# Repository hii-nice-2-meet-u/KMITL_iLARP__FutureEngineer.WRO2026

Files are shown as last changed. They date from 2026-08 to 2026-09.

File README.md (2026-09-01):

# **KMITL iLARP — WRO Future Engineers 2026**

> Autonomous mobile robot developed by **KMITL iLARP** for the
> **World Robot Olympiad 2026 — Future Engineers** category.

---

## **Team**

**KMITL iLARP** — World Robot Olympiad 2026, Future Engineers category.

The repository identifies the team as **KMITL iLARP**. Individual names and
roles are not stored in the source tree.

## **Robot Images**

The robot combines camera vision, LiDAR, odometry, and model-based control in a
compact four-wheel platform. Explore the complete six-view build below or open
the full-resolution originals in [`v-photos/`](v-photos/).

<table>
  <tr>
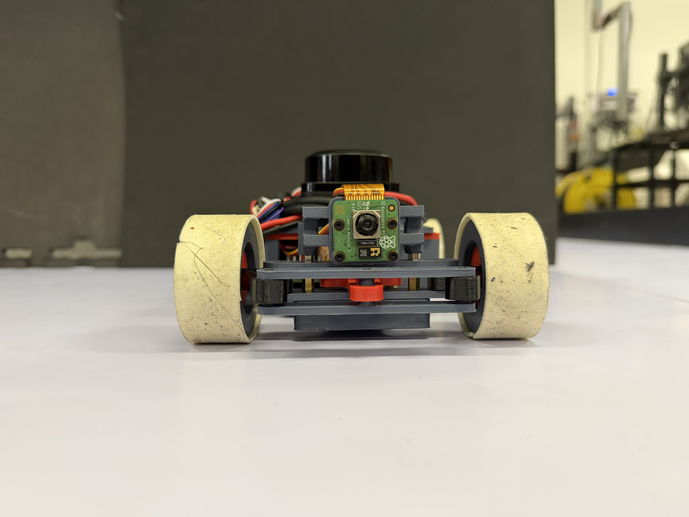
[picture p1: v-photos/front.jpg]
Robot front view
    <td align="center"><br><sub><strong>Front</strong> </sub></td>
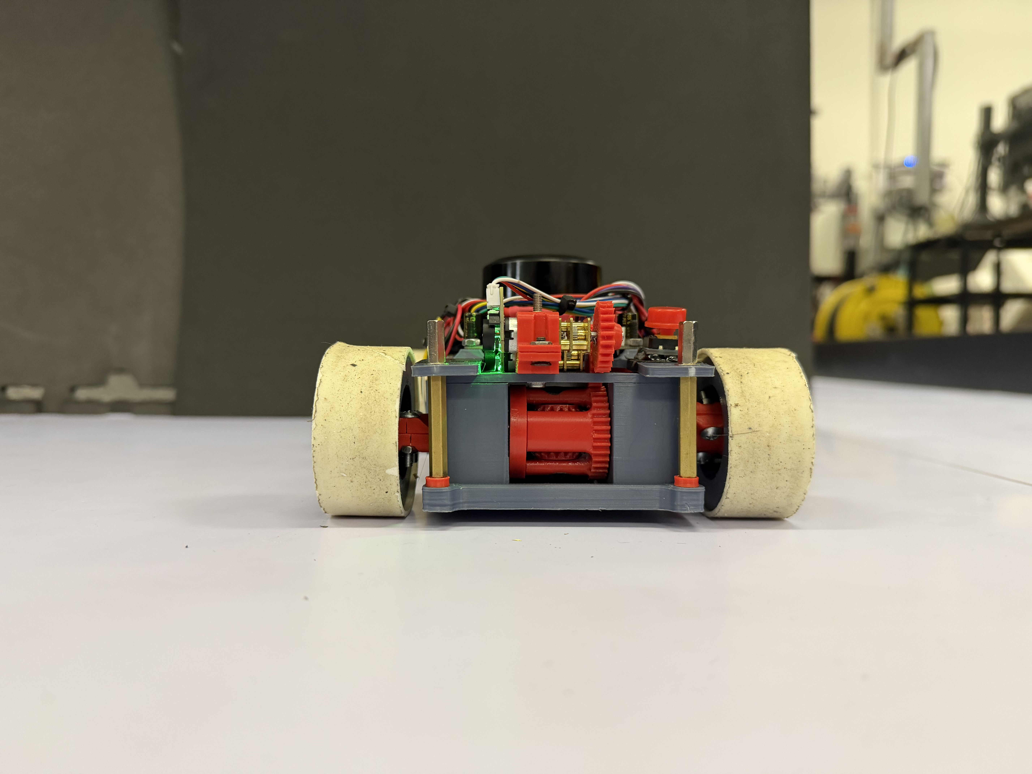
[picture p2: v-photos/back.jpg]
Robot back view
    <td align="center"><br><sub><strong>Back</strong> </sub></td>
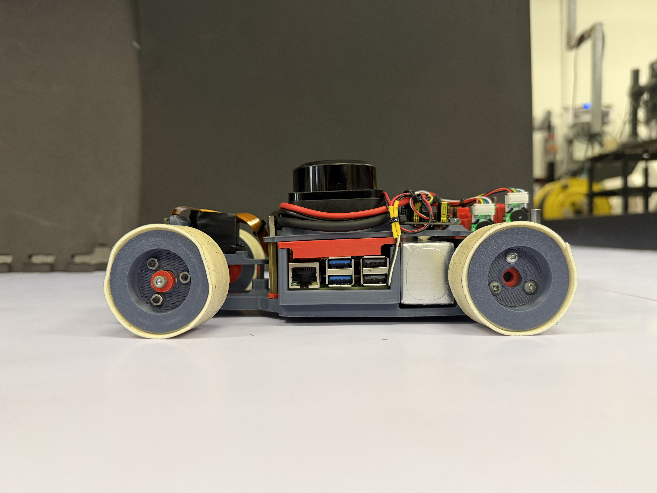
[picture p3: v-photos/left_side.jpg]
Robot left-side view
    <td align="center"><br><sub><strong>Left side</strong> </sub></td>
  </tr>
  <tr>
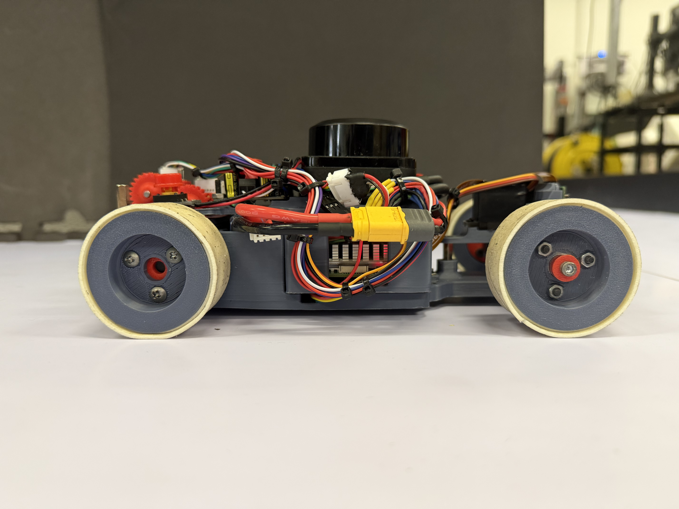
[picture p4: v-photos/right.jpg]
Robot right-side view
    <td align="center"><br><sub><strong>Right side</strong> </sub></td>
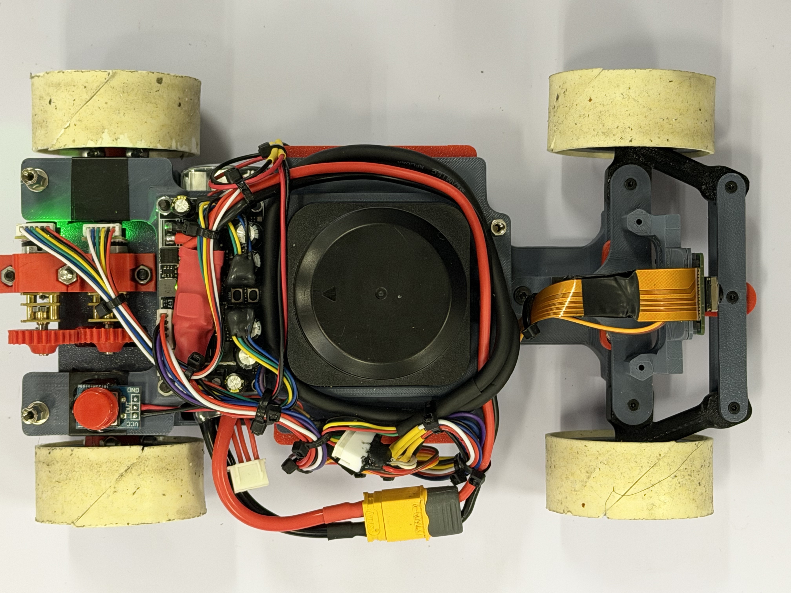
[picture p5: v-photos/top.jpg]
Robot top view
    <td align="center"><br><sub><strong>Top</strong> · Sensor layout</sub></td>
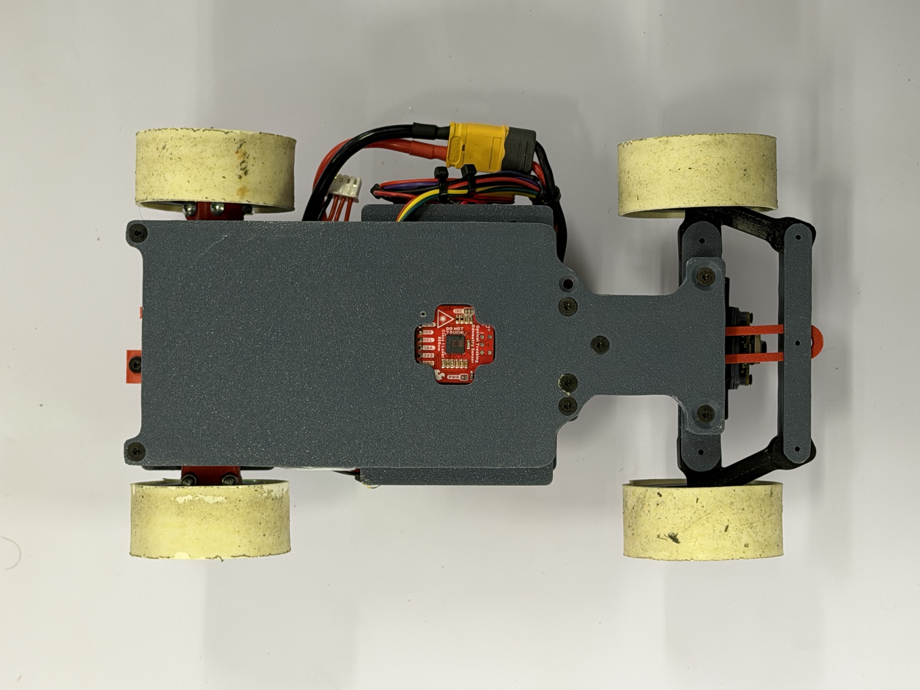
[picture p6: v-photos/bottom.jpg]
Robot bottom view
    <td align="center"><br><sub><strong>Bottom</strong> </sub></td>
  </tr>
</table>

## **Performance Video**

Open Challenge link:

Obstacle Challenge link:

## **Documentation**

Detailed per-subsystem engineering documentation lives in
[`docs/`](docs/README.md). Quick links:
[Vision](docs/vision/README.md) ·
[LiDAR](docs/lidar/README.md) ·
[Odometry](docs/odometry/README.md) ·
[Perception](docs/perception/README.md) ·
[Navigation](docs/navigation/README.md) ·
[Control](docs/control/README.md) ·
[SPI](docs/spi/README.md) ·
[Logging](docs/logging/README.md) ·
[Software Architecture](docs/software/README.md) ·
[Mechanical](docs/mechanical/README.md) ·
[Electronics](docs/electronics/README.md).

---

## **Project Overview**

This project presents the design and implementation of an autonomous mobile robot for the **WRO Future Engineers 2026 competition**.

The system integrates:

- Computer Vision for object detection and classification
- LiDAR-based environment perception
- IMU and odometry for motion stability
- Sensor fusion for robust decision making
- Model-based motion control

The robot is designed to operate in structured track environments while maintaining robustness under dynamic obstacles and varying lighting conditions.

---

## **System Architecture**

```mermaid
flowchart TD
    CAM[Camera] --> CV[Vision Module]
    LIDAR[RPLIDAR S3] --> LIDAR_PROC[LiDAR Module]
    IMU[IMU + Odometry] --> STATE[State Estimation]

    CV --> FUSION[Sensor Fusion Layer]
    LIDAR_PROC --> FUSION
    STATE --> FUSION

    FUSION --> NAV[Navigation System]
    NAV --> CTRL[Motion Controller]

    CTRL --> STEER[Steering]
    CTRL --> DRIVE[Drive Motor]
```

### System Design Philosophy

The system is built on multi-sensor redundancy, where each sensor contributes a different perspective:

1. Camera → semantic understanding (what and where)
2. LiDAR → geometric understanding (distance and structure)
3. IMU + Odometry → motion consistency (stability and heading)

This separation ensures robustness even when one sensor is degraded.

---

## **Computer Vision System**

The vision system is implemented in C++ with OpenCV, using libcamera/LCCV for image acquisition.

### Processing Pipeline

```text
Frame Capture
   ↓
Color Space Conversion (BGR → HSV)
   ↓
Color Segmentation (Red / Green)
   ↓
Morphological Filtering
   ↓
Contour Extraction
   ↓
Geometric Validation
   ↓
Object Classification
   ↓
Bearing Estimation
```

### Output Features

- Object class (red / green obstacle)
- Bounding box
- Image-space position
- Relative bearing angle

Documentation: `docs/vision/README.md`
Source Code: `code/modules/camera`

---

## **LiDAR Perception System**

The robot uses RPLIDAR S3 for environmental geometry sensing.

### Processing Pipeline

```text
Raw Scan Data
   ↓
Point Filtering
   ↓
Polar → Cartesian Conversion
   ↓
Sector Segmentation
   ↓
Statistical Filtering (Median)
   ↓
Wall Estimation
```

### Output Features

- Front distance
- Left / Right distance
- Wall angle estimation
- Track boundary detection

Documentation: `docs/lidar/README.md`
Source Code: `code/modules/lidar`

---

## **IMU and Odometry System**

The motion estimation system combines:

- IMU angular velocity
- Wheel odometry
- Drift correction logic

### Responsibilities

- Heading stabilization
- Short-term pose estimation
- Motion smoothing for control layer

Documentation: `docs/odometry/README.md`
Source Code: `code/modules/otos`

---

## **Navigation System**

The navigation system operates as a state-driven decision engine.

### Open Challenge Strategy

```text
LiDAR Geometry
   ↓
Wall Alignment
   ↓
Track Center Estimation
   ↓
Trajectory Generation
   ↓
Steering Control
```

### Obstacle Challenge Strategy

```text
Camera (Object Detection)
        ↓
LiDAR (Geometry Context)
        ↓
IMU + Odometry (Stability)
        ↓
Sensor Fusion Layer
        ↓
Navigation State Machine
        ↓
Path Decision
```

Documentation: `docs/navigation/README.md` (state machine, corner trajectory, track map)
Source Code: `code/modules/navigation`

---

## **Motion Control System**

The motion controller converts navigation outputs into actuator commands.

### Components

- Steering control (servo-based)
- Drive motor control
- Speed regulation
- Stability correction loop

Documentation: `docs/control/README.md` (PID + Stanley) · `docs/spi/README.md` (STM32 link)
Source Code: `code/control`, `code/modules/spi`

---

## **Software Architecture**

The system is implemented in C++17 and structured into modular components.

```text
code/
├── common/              # direction.hpp (DrivingDirection, TurnDirection)
├── app/
│   ├── _challenge/open/ # open_challenge_main (learn+replay) + actuator
│   ├── test_camera/ test_lidar/ test_perception/ test_otos/ test_spi/
│   └── adjust_HSV/ adjust_white/ camera_tuner/
├── modules/
│   ├── camera/          # CameraModule + CameraProcessor
│   ├── lidar/           # LidarModule + LidarProcessor (walls, obstacles, parking)
│   ├── otos/            # OTOS odometry + LinuxI2C
│   ├── perception/      # camera + LiDAR fusion → FusedObstacle
│   ├── navigation/      # state machine, corner trajectory, init_direction, track_map
│   ├── spi/             # SPI master → STM32 (motor/servo/battery)
│   └── logging/         # async CSV telemetry (Logger V1)
├── control/             # PID + Stanley controllers
├── external/            # git submodules (see .gitmodules)
│   ├── LCCV/ rplidar_sdk/ OTOS/ SparkFunToolkit/
├── utils/               # RingBuffer.hpp
├── build_n_deploy.sh
├── CMakeLists.txt
├── Dockerfile.compile
└── Dockerfile.cross
```

See [`docs/software/README.md`](docs/software/README.md) for the full
architecture, threading model, and module/processor split.

### Core Technologies

| No  | Technology  | Purpose |
| --- | --- | --- |
| 1 | C++17 | Core system implementation |
| 2 | OpenCV | Vision processing |
| 3 | libcamera | Camera interface |
| 4 | LCCV | Camera wrapper |
| 5 | RPLIDAR SDK | LiDAR interface |
| 6 | CMake | Build system |
| 7 | Docker | Cross-platform build environment |

---

## **Build & Deploy**

The robot runs on a **Raspberry Pi 5 (arm64)**. The code is cross-compiled on a
development machine inside Docker and then copied to the Pi — see
[`docs/software/README.md`](docs/software/README.md) for details.

**1. Clone with submodules** (the SDKs under `code/external/` are git
submodules):

```bash
git clone --recurse-submodules <repo-url>
# or, if already cloned:
git submodule update --init --recursive
```

**2. Cross-build and deploy** (edit `PI_USER` / `PI_IP` / `PI_TARGET_DIR` at the
top of the script first):

```bash
cd code
./build_n_deploy.sh          # incremental cross-build + rsync to the Pi
./build_n_deploy.sh cross    # (re)build the cross-compiler Docker image
./build_n_deploy.sh clean    # remove build artifacts
```

The script runs CMake + Ninja (with ccache) inside the `cross-pi` container,
installs to `code/dist/install`, then `rsync`s the result to the Pi over SSH.

The deployment script targets Raspberry Pi 5, but the exact OS image and
runtime package list are not recorded in this repository. The installed Open
Challenge executable is `challenge/open/open_challenge_main`; test and tuning
executables are installed from their corresponding `code/app/*/CMakeLists.txt`.

---

## **Mechanical Design**

The mechanical system is designed in SolidWorks with focus on:

- Compact chassis design
- Stable weight distribution
- Efficient steering geometry
- Modular sensor mounting

### Components

1. Chassis structure
2. Steering mechanism
3. Differential drivetrain
4. Motor mounts
5. Sensor mounts (Camera + LiDAR)

CAD Files: `CAD/`
Documentation: `docs/mechanical/README.md`

---

## **Hardware System**

| No  | Component | Function |
| --- | --- | --- |
| 1 | Raspberry Pi | Main compute unit |
| 2 | Camera | Vision sensing |
| 3 | RPLIDAR S3 | Distance and geometry sensing |
| 4 | IMU | Orientation tracking |
| 5 | Wheel Odometry | Motion estimation |
| 6 | Servo Motor | Steering control |
| 7 | DC Motor | Propulsion |

Documentation: `docs/electronics/README.md`

---

## **Development Tools**

### Vision Tools

- adjust_HSV → color calibration
- adjust_white → white balance tuning
- camera_tuner → camera parameter tuning
- test_camera → camera validation

### LiDAR Tools

- test_lidar → scan validation and debugging

Tools Directory: `code/app/`

---

## **Repository Structure**

```text
KMITL_iLARP__FutureEngineer.WRO2026/
├── CAD/                 # SolidWorks / STEP mechanical models
├── code/
│   ├── common/          # shared enums
│   ├── app/             # challenge programs + test & calibration tools
│   ├── modules/         # camera, lidar, otos, perception, navigation, spi, logging
│   ├── control/         # PID + Stanley
│   ├── external/        # vendored SDKs (git submodules)
│   └── utils/           # RingBuffer
├── docs/
│   ├── vision/  lidar/  odometry/       # perception
│   ├── perception/  navigation/  control/  spi/  logging/   # decision + actuation
│   ├── software/                        # architecture, build/deploy
│   ├── mechanical/  electronics/        # hardware
│   └── resources/                       # images referenced by the docs
├── t-photos/  v-photos/  video/         # required WRO submissions
├── README.md
└── LICENSE
```

---

## **Documentation Structure**

1. Each subsystem has its own documentation
2. Main README acts as system overview only
3. Technical details are separated into modules

Full documentation index: `docs/README.md`

---

## **WRO Future Engineers 2026**

The system is designed under the principle:

> Vision provides semantics, LiDAR provides geometry, IMU provides stability, and fusion enables intelligence.

---

KMITL iLARP — WRO Future Engineers 2026
Autonomous Robotics • Computer Vision • LiDAR • Embedded Systems

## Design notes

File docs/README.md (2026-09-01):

# Documentation Index — KMITL iLARP · WRO Future Engineers 2026

This folder contains the detailed engineering documentation for each subsystem
of the robot. The top-level [`README.md`](../README.md) is the system overview;
the documents below go into the reasoning, parameters, and implementation of
each module.

> **Note on scope.** Every technical document here is derived directly from the
> source code in [`code/`](../../../code). Where a value or rationale is not present
> in the codebase (for example measured current draw or final mechanical
> justification), the document states that limitation instead of inventing a
> measurement.

## Signal flow (current architecture)

```
                 ┌──────────┐   ┌──────────┐   ┌────────┐
   sensors  ───▶ │ camera   │   │ lidar    │   │ otos   │
                 │ module   │   │ module   │   │ (pose) │
                 └────┬─────┘   └────┬─────┘   └───┬────┘
                      ▼              ▼             │
                 CameraProcessor  LidarProcessor   │
                      │              │             │
                      └──────┬───────┘             │
                             ▼                     │
                        ┌──────────┐               │
                        │perception│◀──────────────┤ (pose for world mapping)
                        │ (fusion) │               │
                        └────┬─────┘               │
                             ▼                     ▼
                        ┌─────────────────────────────┐
                        │ navigation_controller        │
                        │  · init_direction (CW/CCW)   │
                        │  · Stanley + PID (control/)   │
                        │  · geometric corner + FF      │
                        │  · track_map (learn/replay)   │
                        └───────────────┬──────────────┘
                                        ▼ NavigationCommand (speed, steering)
                        ┌───────────────────────────────┐
                        │ actuator (open challenge app)  │
                        │  → spi_master → STM32 (motor/servo)
                        └───────────────────────────────┘
                                        │
                        logging/ taps every stage → CSV + events
```

## Subsystem documents

| # | Document | Covers | Source code |
|---|---|---|---|
| 1 | [Vision](vision/README.md) | Camera capture, HSV segmentation, object detection, bearing | [`code/modules/camera`](../../../code/modules/camera) |
| 2 | [LiDAR](lidar/README.md) | Scan acquisition, line fitting, wall/obstacle/parking resolution | [`code/modules/lidar`](../../../code/modules/lidar) |
| 3 | [Odometry](odometry/README.md) | SparkFun OTOS optical pose over I²C | [`code/modules/otos`](../../../code/modules/otos) |
| 4 | [Perception (fusion)](perception/README.md) | Camera↔LiDAR association, obstacle colour, world mapping | [`code/modules/perception`](../../../code/modules/perception) |
| 5 | [Navigation](navigation/README.md) | State machine, corner trajectory, direction search, track map | [`code/modules/navigation`](../../../code/modules/navigation) |
| 6 | [Control](control/README.md) | PID + Stanley steering controllers | [`code/control`](../../../code/control) |
| 7 | [SPI link](spi/README.md) | RPi ↔ STM32 command protocol | [`code/modules/spi`](../../../code/modules/spi) |
| 8 | [Logging](logging/README.md) | Async CSV telemetry, events, walls, corners | [`code/modules/logging`](../../../code/modules/logging) |
| 9 | [Software Architecture](software/README.md) | Module/processor split, threading, build & deploy | [`code/`](../../../code) |
| 10 | [Mechanical](mechanical/README.md) | Chassis, steering, drivetrain, CAD inventory | [`CAD/`](../../../CAD) |
| 11 | [Electronics](electronics/README.md) | Compute, sensors, wiring, power budget | — |

## How this maps to the WRO documentation rubric (Appendix C)

The WRO Future Engineers rubric scores the repository on five criteria
(0/2/4/6 each, 30 total):

| Rubric criterion | Where to look |
|---|---|
| 1. Mobility & mechanical design | [Mechanical](mechanical/README.md) |
| 2. Power & sensor architecture | [Electronics](electronics/README.md), [Odometry](odometry/README.md) |
| 3. Software architecture & obstacle strategy | [Navigation](navigation/README.md), [Control](control/README.md), [Perception](perception/README.md), [Vision](vision/README.md), [LiDAR](lidar/README.md) |
| 4. Systems thinking & engineering decisions | "Decision log" sections in each document |
| 5. Reproducibility & GitHub quality | This index + per-module READMEs + top-level README |

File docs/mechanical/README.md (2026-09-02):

# Mechanical Design

Chassis, steering, and drivetrain of the robot, and an inventory of the CAD
files that describe them.

**CAD files:** [`CAD/`](../../../../CAD) (SolidWorks `.SLDPRT`/`.SLDASM` +
neutral `.STEP`/`.stp`)

---

## 1. Design goals

The mechanical platform is built around four goals stated in the top-level
README:

- compact chassis that fits within the WRO Future Engineers size limits,
- stable weight distribution for predictable handling,
- efficient steering geometry,
- modular mounts so the camera and LiDAR can be positioned and re-positioned.

---

## 2. Drivetrain

A **rear differential drive** driven by **two** N20 gear-motors mounted
mirror-imaged onto a common input, feeding a purpose-built differential gearset:

- **Motors:** two N20 gear-motors (`CAD/Motor_N20.SLDPRT`, instanced twice in
  the assembly). The pair was adopted to supply drive torque the earlier
  single-motor layout could not. Because they are mounted mirrored, their output
  shafts turn in opposite directions for the same electrical command, and the
  firmware accounts for the inversion; they are **not** one-motor-per-wheel.
- **Differential:** custom-designed gearset in
  [`CAD/DifferentialGear`](../../../../CAD/DifferentialGear):
  - `DifferentialGear__RingGear.SLDPRT` + `...RingGearCap.SLDPRT`
  - `DifferentialGear__Pinions.SLDPRT`
  - `DifferentialGear__SideGear.SLDPRT`
  - `Nut__M3_L27.5_.SLDPRT`

A differential lets the two driven wheels rotate at different speeds through a
turn, avoiding the scrubbing and heading disturbance a locked axle would cause.
The two motors join *before* the differential, at its input, so differential
action between the left and right wheels is preserved.

---

## 3. Steering

Front steering actuated by an **MG90S** micro servo. The steering linkage
knuckles are in [`CAD/MG90`](../../../../CAD/MG90):

- `MG90S_Servo.STEP` — the servo (source: GrabCAD, see `CAD/MG90/soures.txt`)
- `ShoulderUnidirectional.STEP`
- `Shoulder_BiDirectional.STEP`
- `Shoulder_FourDirected.STEP`

The multiple "shoulder" variants are steering-knuckle iterations — evidence of
design iteration on the steering geometry.

---

## 4. Sensor & component mounting

CAD models of the mounted hardware are included so the assembly and sensor
positions are fully described:

| Component | CAD file |
|---|---|
| RPLIDAR S3 | `CAD/RPLIDAR_S3.SLDASM` / `.stp` |
| Raspberry Pi Camera Module 3 | `CAD/RaspburryPi_Camera_Module3.SLDPRT` |
| SparkFun OTOS (PAA5160E1, SEN-24904) | `CAD/SparkFunOpticalTrackingOdometrySensor_...SLDPRT` / `.step` |
| CN3903 (power module) | `CAD/CN3903.SLDASM` / `.STEP` |
| Bearings | `CAD/Bearing_MR128ZZ.SLDPRT`, `CAD/Bearing_MR63ZZ.SLDPRT` |
| Fasteners | `CAD/Nut__M3_Female_.SLDPRT`, `CAD/NutRing__3M.SLDPRT` |
| Test object (marker stand-in) | `CAD/Object/BOX_5x5x10__.SLDPRT` / `.STEP` |

---

## 5. Decision log (rubric criterion 1)

Already inferable from the CAD:

- **Differential drive** — allows different wheel speeds in turns, reducing tire
  scrub and heading upset compared with a fixed axle.
- **Servo-steered front axle (Ackermann-style)** with a dedicated linkage,
  rather than skid/differential steering — closer to a real "self-driving car"
  and matches the category's kinematics focus.
- **Custom differential + iterated steering shoulders** — the multiple shoulder
  versions show the geometry was revised, not adopted blindly.

The CAD directory contains SolidWorks and STEP source files, including several
steering-linkage iterations. It does not contain exported renders, STL files,
measured dimensions, mass, motor gearing data, torque/speed tests, or a weight
distribution record. Those values must be taken from the final assembled robot;
they are not inferred here from filenames or CAD metadata.

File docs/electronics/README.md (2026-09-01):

# Electronics & Power

Compute, sensing, and actuation hardware, how it is wired, and the power budget.

---

## 1. Component overview

| # | Component | Role | Interface | CAD / ref |
|---|---|---|---|---|
| 1 | Raspberry Pi 5 (arm64) | Main compute (perception, navigation) | — | deploy target in `build_n_deploy.sh` |
| 2 | STM32 (MCU) | Real-time actuation: motor + servo + battery | SPI slave | Exact part number is not recorded in the source tree |
| 3 | Raspberry Pi Camera Module 3 | Vision sensing | CSI (libcamera) | `CAD/RaspburryPi_Camera_Module3.SLDPRT` |
| 4 | RPLIDAR S3 | Distance & geometry sensing | UART `/dev/ttyAMA0` @ 1 Mbaud | `CAD/RPLIDAR_S3.SLDASM` |
| 5 | SparkFun OTOS (PAA5160E1) | Optical odometry (pose) | I²C | `CAD/SparkFunOpticalTracking...SLDPRT` |
| 6 | CN3903 | Power / battery management | — | `CAD/CN3903.SLDASM` |
| 7 | MG90S servo | Steering actuator | PWM (driven by STM32) | `CAD/MG90/MG90S_Servo.STEP` |
| 8 | N20 gear-motor | Drive / propulsion | motor driver (driven by STM32) | `CAD/Motor_N20.SLDPRT` |

The compute is **split**: the Pi 5 runs perception + navigation; a separate
**STM32** executes the low-level motor/servo commands and reports battery
voltage, connected to the Pi over **SPI** (15 MHz, mode 0). Camera, LiDAR, and
OTOS have driver modules on the Pi; the servo and motor are commanded through the
SPI link — see the [SPI doc](../spi/README.md).

---

## 2. Software ↔ hardware map

| Subsystem | Hardware | Bus / port | Code |
|---|---|---|---|
| Vision | Camera Module 3 | CSI via libcamera/LCCV | [`modules/camera`](../../../../code/modules/camera) |
| LiDAR | RPLIDAR S3 | UART `/dev/ttyAMA0`, 1,000,000 baud | [`modules/lidar`](../../../../code/modules/lidar) |
| Odometry | OTOS | I²C (`/dev/i2c-*`) | [`modules/otos`](../../../../code/modules/otos) |
| Actuation link | STM32 | SPI master (15 MHz, mode 0) | [`modules/spi`](../../../../code/modules/spi) |
| Steering | MG90S servo | PWM from STM32 (pulse 1000–2100 µs) | via SPI `SERVO_PULSE` |
| Drive | N20 motor | motor driver from STM32 | via SPI `M1_POW` |

---

## 3. Wiring diagram

The repository does not contain a wiring drawing. The electrical topology
implemented by the software is: battery and regulation feed the Pi, camera,
LiDAR, and OTOS; the Pi communicates with the STM32 over SPI; and the STM32
drives the motor and steering servo. Pin-level wiring and voltage rails must be
checked against the assembled robot before publication.
>
The final wiring record should show, at minimum: battery → CN3903 / regulation
→ Pi 5, and how the camera (CSI), LiDAR (USB), OTOS (I²C), servo (PWM), and
motor driver are connected, including voltage rails.

---

## 4. Power budget

The source tree does not include measured current data or a battery
specification, so a numerical power budget would be misleading. Record the
values from the assembled hardware before using this table for electrical
sign-off:

| Load | Voltage | Typical current | Peak current | Notes |
|---|---|---|---|---|
| Raspberry Pi 5 | 5 V | not recorded | not recorded | Higher under CV load |
| RPLIDAR S3 | not recorded | not recorded | not recorded | Motor + sensor |
| Camera Module 3 | 3.3 V | not recorded | not recorded | CSI camera power is supplied by the Pi |
| OTOS | 3.3 V | not recorded | not recorded | I²C sensor |
| MG90S servo | not recorded | not recorded | not recorded | Stall current matters |
| N20 motor | not recorded | not recorded | not recorded | Via driver |
| **Total** | | **not calculated** | **not calculated** | |

Also state: **battery** chemistry / voltage / capacity (mAh), how it is
regulated (the CN3903 / any buck converters), and the resulting **estimated run
time**.

---

## 5. Calibration & noise considerations

The vision intrinsics currently live in `camera_processor.hpp`. The repository
does not include the calibration record. OTOS mounting offsets, electrical-noise
mitigation, grounding, shielding, and lighting tests are also not recorded and
must be documented from the assembled robot and its test results.

---

## 6. Decision log (rubric criterion 2 & 4)

Already visible in the code:

- **Raspberry Pi 5 as sole compute** — enough headroom to run OpenCV vision and
  LiDAR geometry on-board; cross-compiled to keep the Pi free of build load.
- **RPLIDAR at 1 Mbaud over USB serial** — the S3's rate for dense scans.
- **OTOS on I²C in meters/radians** — matches LiDAR/camera units for fusion.

The split architecture keeps perception and navigation on the Pi while the
STM32 handles time-sensitive actuation. Camera, LiDAR, and OTOS provide
complementary semantic, geometric, and motion information. Current, weight,
and processing-time measurements are not stored in the source tree.

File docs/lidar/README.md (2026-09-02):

# LiDAR System

Turns raw 2-D laser scans into a compact geometric description of the track:
the left, right, and front walls, plus any obstacle markers standing inside the
lane.

**Source code:** [`code/modules/lidar`](../../../../code/modules/lidar)
· Acquisition: [`lidar_module.cpp`](../../../../code/modules/lidar/lidar_module.cpp)
· Processing: [`lidar_processor.cpp`](../../../../code/modules/lidar/lidar_processor.cpp)
· Shared types: [`lidar_struct.hpp`](../../../../code/modules/lidar/lidar_struct.hpp)

Sensor: **RPLIDAR S3** (SLAMTEC), driven through the official `rplidar_sdk`.

### Physical mount convention

The assembled robot mounts the RPLIDAR with its raw-angle-zero arrow pointing
to the rear. RPLIDAR's raw 0° is the direction of that arrow, so the robot's
front is raw 180°. `polar2cartesian()` intentionally applies the 180° mount
compensation (`x = -d·sin(angle)`, `y = -d·cos(angle)`), leaving **+Y as the
robot-forward axis**. This was confirmed by M-1 on 2026-09-02; do not remove
the minus signs.

---

## 1. Responsibilities

Like the vision subsystem, LiDAR is split into acquisition and processing:

- **`LidarModule`** — owns the serial connection and the scan thread. It
  converts the SDK's fixed-point measurement nodes into plain
  `LidarPoint{angle_deg, distance_m, quality}` values and publishes timestamped
  scans.
- **`LidarProcessor`** — a stateless pipeline that converts one scan into
  `ProcessedLidarData`: fitted line segments, resolved walls, and obstacle
  segments.

---

## 2. Acquisition (`LidarModule`)

| Parameter | Default | Notes |
|---|---|---|
| Serial port | `/dev/ttyUSB0` (module default) | The Open Challenge apps use `/dev/ttyAMA0` (Pi GPIO UART) |
| Baud rate | 1,000,000 | RPLIDAR S3 |
| Buffer | `RingBuffer<TimedLidarData, 10>` | Newest-wins |

Flow (`lidar_module.cpp`):

1. `initialize()` creates a serial channel and the SLAMTEC driver, then
   `connect()`s. Failures are reported and cleaned up.
2. `start()` sets the motor speed and calls `startScan()`, then spawns
   `scan_loop()` on its own thread.
3. `scan_loop()` repeatedly `grabScanDataHq()` → `ascendScanData()` (sort by
   angle) → `processScan()`.
4. **Health watchdog.** If `grabScan` fails 3 times in a row, `checkHealth()` is
   queried and the device health / error code is logged. This surfaces motor or
   comms problems instead of silently stalling.

### Fixed-point conversion

The SDK returns fixed-point fields, converted in `processScan()`:

```
angle_deg   = angle_z_q14 * 90 / 2^14
distance_m  = dist_mm_q2 / 1000 / 2^2
quality     = node.quality
```

Consumers use `get_latest()` (non-blocking) or `wait_for_data()` (blocks until a
new scan), the same pattern as the camera module.

---

## 3. Processing pipeline (`LidarProcessor`)

```
TimedLidarData (polar points)
   │
   ▼  filter invalid points (quality, min distance)
   ▼  polar → cartesian
Cartesian points
   │
   ▼  split-and-merge → point groups
   ▼  PCA line fit per group → LineSegment
   ▼  merge collinear aligned segments
Line segments
   │
   ├─▶ resolve_track_walls → left / right / front walls
   ├─▶ find_parking_wall  → optional parking-lot wall
   └─▶ detect_obstacles   → obstacle markers (with bearing_rad())
ProcessedLidarData
```

`ProcessedLidarData` now carries `line_segments`, `walls` (`ResolvedWalls`), an
optional `parking_wall`, and `obstacles`. Each `ObstacleObject` exposes
`bearing_rad() = atan2(center.x, center.y)`, which the perception layer uses to
associate it with a camera detection.

### 3.0 Motion deskew (P-22 enabled)

Each scan is deskewed into its scan-end frame using the measured OTOS forward
velocity, yaw rate, and LiDAR revolution period. M-1 confirms that forward is
robot +Y, matching the sign in `LidarProcessor::deskew()`. The first scan, which
has no measured period yet, intentionally remains un-deskewed.

The old controller-injected `wall_correction_rad` path has been removed from
LiDAR processing. Geometry is no longer rotated using the navigation target
heading; the telemetry field is retained as a deprecated zero column for CSV
schema compatibility.

### 3.1 Point filtering & coordinate frame

`process()` now takes the tuning constants and optional `ScanMotion`; it no
longer accepts `heading_error_rad`. Full signature:

```cpp
process(data, min_segment_point = 5, max_line_error_m = 0.035,
        max_point_gap_m = 0.10, max_angle_diff = 3.0,
        max_collinear_error_m = 0.03, max_segment_gap_m = 0.05,
        motion = ScanMotion{})
```

> **Logged geometry is now in the deskewed robot frame.** The deprecated
> `wall_correction_rad` telemetry column is always zero after P-22; it remains
> only to preserve the existing CSV column layout.

`is_valid_point()` drops points with `quality < 10`, non-finite range/angle,
`distance < 0.015 m`, or `distance > 3.0 m`. The decision lives in
`classify_point()`, which also tags each rejection as quality- or range-based so
the per-scan `lidar_points_rejected_quality`/`_range` telemetry counts a mis-set
threshold without persisting the raw scan.

`polar2cartesian()` uses the robot frame **+X = right, +Y = forward**:

```
x = distance · sin(angle)
y = distance · cos(angle)
```

### 3.2 Split-and-merge line fitting

Implemented recursively in `split_line_segments_recursive()`. For a run of
points it:

1. **Gap split** — if the distance between two consecutive points exceeds
   `MAX_POINT_GAP_M`, split there (the wall is not continuous).
2. **Deviation split** — otherwise find the point farthest from the
   straight line joining the run's endpoints; if that deviation exceeds
   `MAX_LINE_ERROR_M`, split at that point (Douglas–Peucker style).
3. Otherwise the run is accepted as one segment.

Runs shorter than `MIN_SEGMENT_POINTS` are discarded.

| Constant | Value |
|---|---|
| `MIN_SEGMENT_POINTS` | 5 |
| `MAX_LINE_ERROR_M` | 0.035 m |
| `MAX_POINT_GAP_M` | 0.11 m |

### 3.3 Line fitting (`fit_line_segment`)

Each accepted group is fitted with **total least squares (PCA)**, not ordinary
least squares, so vertical walls are handled correctly:

```
θ = 0.5 · atan2( 2·Sxy , Sxx − Syy )
```

The segment stores its direction/normal, the line constant `c`, its two
projected endpoints, and its **RMS error**. Segments whose RMS error exceeds
`MAX_LINE_ERROR_M` are rejected after fitting as well.

### 3.4 Merging aligned segments (`merge_aligned_segments`)

A real wall often breaks into several segments. Two segments are merged when
**all** of these hold:

| Test | Threshold |
|---|---|
| Angle difference | ≤ 5° |
| Collinearity (perp. distance of one center to the other's line) | ≤ 0.02 m |
| End-to-end gap | ≤ 0.05 m |

The merged segment spans the extreme projections of all four endpoints along the
common direction.

### 3.5 Resolving walls (`resolve_track_walls`)

Segments longer than `MIN_WALL_LENGTH_M = 0.25 m` are classified by orientation
(within `±15°`):

- **Vertical-ish** segments → **left** wall if their center x < 0, else
  **right** wall.
- **Horizontal-ish** segments with center y > 0 → **front** wall.

For each side the wall with the **smallest perpendicular distance** (i.e. the
closest) wins. The result is a `ResolvedWalls{left, right, front}`, each
optional.

`resolve_inner_outer()` maps left/right to **inner/outer** depending on the
`DrivingDirection` (CLOCKWISE vs COUNTER_CLOCKWISE), so the same logic works
regardless of which way the round is run.

### 3.6 Obstacle detection (`detect_obstacle_segments`)

A segment is treated as an obstacle marker only if it is **not** part of a wall
and is the right size:

- rejected if it *is* one of the resolved walls (`is_same_segment`) or is a
  fragment lying on a wall (`is_wall_fragment`);
- kept only if `0.028 m ≤ length ≤ 0.08 m` and its center is in front
  (`y > 0`);
- nearby detections (within 0.08 m) are merged so one marker yields one
  obstacle.

| Constant | Value |
|---|---|
| `MIN_OBSTACLE_SEGMENT_LENGTH_M` | 0.028 m |
| `MAX_OBSTACLE_SEGMENT_LENGTH_M` | 0.08 m |
| `SAME_OBSTACLE_DISTANCE` | 0.08 m |
| Wall-fragment max distance | 0.04 m |

---

## 4. Debug tools

- [`code/app/test_lidar`](../../../../code/app/test_lidar) renders a top-down debug map
  (1 m = 300 px): raw segments in gray, resolved walls in green, obstacles in
  red with distance/bearing labels, plus per-frame processing time.
- [`code/app/test_perception`](../../../../code/app/test_perception) exercises the
  full LiDAR + camera **fusion** path — see the
  [Perception](../perception/README.md) doc.

These are the main tools for verifying the pipeline against a real track.

---

## 5. Decision log (rubric criterion 4)

Already visible in the code:

- **Split-and-merge + PCA** instead of a Hough transform — gives explicit,
  bounded line segments with endpoints and an RMS error to threshold on, which
  is exactly what wall/obstacle resolution needs.
- **Total least squares** rather than y-on-x least squares — the latter blows up
  for near-vertical walls (infinite slope); TLS does not.
- **Closest-segment-wins** for wall selection — the nearest parallel surface is
  the actual track wall; farther parallel returns are noise or the opposite
  wall.
- **Inner/outer abstraction** — decouples the geometry from the run direction so
  navigation logic is written once.

The thresholds are defined in `LidarProcessor::process()` and describe the
current geometric filters. The repository contains no tuning log, measured
processing rate, real-track scan count, or failure-case report, so those values
are not presented as measured performance here.

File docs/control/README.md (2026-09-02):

# Control

Low-level controllers used by the navigation layer: a general PID and a Stanley
lateral controller built on top of it.

**Source code:** [`code/control`](../../../../code/control)
· PID: [`pid.cpp`](../../../../code/control/pid.cpp) / [`pid.hpp`](../../../../code/control/pid.hpp)
· Stanley: [`stanley_controller.cpp`](../../../../code/control/stanley_controller.cpp) / [`.hpp`](../../../../code/control/stanley_controller.hpp)

---

## 1. PID (`control::PID`)

A reusable PID with the safety features a real control loop needs:

- **Output clamping** — `min_output` / `max_output`.
- **Integral anti-windup** — the integral term is clamped to
  `min_integral` / `max_integral`, so it cannot wind up while the output is
  saturated.
- **dt handling** — `calculate(setpoint, current)` measures `dt` from a
  `steady_clock`; an explicit `calculate(setpoint, current, dt_s)` overload is
  used when the caller already has a timestep. `dt` is guarded by `max_dt_s`
  (default 0.10 s) so a long gap between calls cannot cause a derivative spike.
- **`reset()`** clears the integral and derivative history between runs.

`PIDConfig` fields: `kp, ki, kd, min_output, max_output, min_integral,
max_integral, max_dt_s`.

The navigation layer instantiates PID **twice**, with different gains, for:
heading hold during a corner (`turn_heading_pid`) and inside the Stanley
controller (`heading_pid`).

> A third instance, `speed_pid` (speed→acceleration), was removed. Its output
> reached no actuator: `ActuatorOutput::apply()` converts `target_speed_mps`
> straight to a motor-RPM command, and the STM32 runs its own closed speed
> loop, so the Pi-side acceleration request was dead code (audit finding F-09).
> Speed on the Pi side is shaped only by the `max_acceleration_mps2` /
> `max_deceleration_mps2` rate limits in `condition_command()`.

---

## 2. Stanley controller (`control::StanleyController`)

Standard Stanley steering law for the Ackermann front axle:

```
delta = heading_error
      + atan2( k · cross_track_error , speed + softening_speed )
```

- **`k`** (cross-track gain, default 1.0; Open Challenge uses 0.85) — how hard to
  correct lateral error.
- **`softening_speed_mps`** (0.20) — prevents divide-by-near-zero and overly
  aggressive steering at low speed.
- **`max_steering_rad`** (default 30°; Open Challenge widens to 45°) — physical
  steering limit; the output is clamped to it.
- The **heading term** is stabilised by an internal PID (`heading_pid`) rather
  than used raw, which damps oscillation.

Sign convention: **negative = LEFT, positive = RIGHT**, matching the navigation
and actuator layers.

---

## 3. Decision log (rubric criterion 4)

Visible in the code:

- **Stanley over pure-pursuit** — Stanley references the front axle and handles
  both cross-track and heading error directly, which suits a wall-following car
  with a LiDAR-measured wall line.
- **PID as a shared primitive** — one well-tested implementation (with
  anti-windup and dt guarding) is reused for heading, speed, and the Stanley
  heading term, instead of three ad-hoc loops.
- **Speed-softened cross-track term** — keeps steering sane at the low speeds
  used in SEARCH_DIRECTION and corner exits.

The source tree records the active gains and logs both raw and shaped steering,
but it does not include step-test results, a before/after comparison, or plots.
Those records should be added only from actual track runs.

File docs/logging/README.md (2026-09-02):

# Logging & Telemetry

Records what the robot sensed, decided, and commanded on every run, so behaviour
can be analysed and re-tuned offline without a debugger on the track.

**Source code:** [`code/modules/logging`](../../../../code/modules/logging)
· Async writer: [`async_csv_writer.cpp`](../../../../code/modules/logging/async_csv_writer.cpp)
· Row types & CSV: [`log_types.cpp`](../../../../code/modules/logging/log_types.cpp) / [`.hpp`](../../../../code/modules/logging/log_types.hpp)
· Loggers: [`telemetry_logger.cpp`](../../../../code/modules/logging/telemetry_logger.cpp), [`wall_logger.cpp`](../../../../code/modules/logging/wall_logger.cpp), [`segment_logger.cpp`](../../../../code/modules/logging/segment_logger.cpp)
· Run metadata: [`run_metadata.cpp`](../../../../code/modules/logging/run_metadata.cpp)
· Offline tools: [`code/tools`](../../../../code/tools)

---

## 1. Design goal

Logging must **not** slow the control loop. All file I/O is pushed to a
background thread; the control thread only enqueues rows.

---

## 2. `AsyncCsvWriter` — the backbone

- Opens a CSV file, writes the header, and spawns a **worker thread**.
- `push(row)` appends to an in-memory queue under a mutex and returns
  immediately.
- The queue is **bounded** (`maximum_queued_rows = 400`, drop-oldest): if the
  disk can't keep up, the oldest rows are dropped and counted rather than
  blocking the robot.
- A background **flush every 1 s** limits data loss on a crash without putting
  I/O on the control thread.
- Write failures are latched and reportable (`has_write_error()`).

> **Durability note:** `flush()` provides OS page-cache durability, not
> `fsync`-level guarantees. A power cut can still lose the last unflushed rows,
> plus whatever remained in the in-memory queue.

---

## 3. The missing-value convention (read this first)

The one rule the schema depends on, documented at the top of `log_types.hpp`:

> **A numeric column of `0` means "measured, and the value was zero" — never
> "not measured".** Any group that can be absent carries a paired `*_valid`
> boolean, written in **every** navigation mode, not only the mode that computes
> it. Consumers must gate on the flag before plotting or averaging.

This exists because the controller builds a fresh `NavigationDebug` each tick, so
an unwritten field would otherwise log a plausible `0`. Before this was enforced,
wall distances read `0` through every corner and made plots look broken. Key
pairs: `outer_distance_m`/`outer_wall_valid`, `inner_distance_m`/
`inner_wall_valid`, `distance_error_m`/`wall_following_active`,
`effective_turn_trigger_m` & `wall_corner_*`/`turn_trigger_evaluated`,
`battery_voltage_v`/`battery_valid`, `camera_process_us`/`camera_process_valid`.
Absence is **never** encoded as `NaN` (it parses inconsistently across tools).

---

## 4. Per-run outputs

Each run gets its own directory (`make_run_directory("logs")`), containing:

| File | Row type | Cadence | Purpose |
|---|---|---|---|
| `run_meta.json` | — | once at start (+ drop counts at exit) | provenance: git commit/dirty, build time, executable, telemetry field count, full config dump (navigation/stanley/PID/actuator, and perception/obstacle for the obstacle app), OTOS scalars actually applied |
| `telemetry.csv` | `TelemetryRow` | per tick (~20 Hz) | full per-tick state (§5) |
| `walls.csv` | `WallRow` | **every mode** | resolved wall segments, with a `mode` column to filter |
| `segments.csv` | `SegmentRow` | every mode | **all** fitted line segments (not just the 3 resolved walls), each tagged LEFT/RIGHT/FRONT/NONE — debugs a mis-classified wall offline |
| `corners.csv` | `CornerRow` | on exit | `TrackMap` corner landmarks snapshot |
| `events.log` | (EventLogger) | sparse | mode transitions and faults, timestamped from run start |

A run **refuses to start** if `run_meta.json` cannot be written — an
unattributable log is worse than none. Drop counts for all three async writers
(telemetry, walls, events) are printed at exit and recorded back into
`run_meta.json`.

---

## 5. `TelemetryRow` contents (94 columns)

Grouped by what each group answers. Every group follows §3.

- **Pose & motion:** `pos_x_m, pos_y_m, heading_rad, measured_speed_mps`.
- **Raw OTOS channels:** `pose_timestamp_us` (same `steady_clock` epoch as the
  LiDAR scan, so scan-to-pose skew is measurable), `otos_velocity_x/y_mps`,
  `otos_yaw_rate_rps`, `otos_accel_x/y_mps2` — the signed velocity, yaw rate and
  acceleration the controller's unsigned `hypot` speed throws away.
- **Wall following:** `outer_distance_m, inner_distance_m, distance_error_m,
  wall_angle_rad, angle_error_rad` + validity flags; `wall_correction_rad` (the
  heading de-rotation applied before classification — subtract to recover raw
  geometry).
- **Turn & corner tracking:** `heading_error_rad, turn_progress,
  turn_feedforward_rad, effective_turn_trigger_m, wall_corner_*`,
  `turn_trigger_source/frames/armed/evaluated`, `replay_gate_suppressed`.
- **Controller internals:** Stanley cross-track/heading terms and integral,
  turn-heading PID output/integral — so PID gains are tunable from a log, not
  only from the summed command.
- **Raw vs shaped command:** `raw_steering_rad` vs `steering_rad`,
  `raw_target_speed_mps` vs `target_speed_mps` — makes the conditioning stage
  tunable.
- **Timing:** `update_dt_s` (clamped) and `raw_update_dt_s` (pre-clamp);
  `lidar_process_us`, `camera_process_us` (per-stage wall-clock).
- **Battery:** `battery_voltage_v` + age, sampled ~1 Hz (blocking SPI read).
- **Obstacle avoidance & fusion:** obstacle active/colour/side/geometry/world
  position; camera-LiDAR fusion counts; `lidar_points_total` and the
  `rejected_quality`/`rejected_range` tallies (a mis-set LiDAR threshold shows
  up here without persisting the raw scan).
- **Actuator output:** `wheel_rpm`, `servo_pulse_us` (sent) and
  `commanded_servo_pulse_us` (pre-step-limit — reveals when `maximum_servo_step_us`
  is clipping). Empty for monitor-only apps.

---

## 6. Clean shutdown

`install_stop_signal_handlers()` / `notify_stop_requested()` let a
`SIGINT`/`SIGTERM` stop a run cleanly — the challenge apps call
`notify_stop_requested()` from their signal handler so the writer threads flush
and join instead of being killed mid-write. `SIGKILL` cannot be caught and loses
the flush interval plus the in-memory queue.

---

## 7. Offline tools ([`code/tools`](../../../../code/tools))

- **`plot_run.py <telemetry.csv> [out]`** — top-down map (speed-coloured
  trajectory, obstacles, per-lap overlay) plus validity-gated signal time series.
  Reads columns from the file header and gates each series on its `*_valid` flag,
  so it renders old and new schemas and draws gaps, not false zeros.
- **`check_run.py <run_dir>`** — automated QA; non-zero exit on any failure.
  Flags per-mode zero-fill, `row_index` gaps, writer drop counts, `dt` outliers,
  a `measured/target` speed ratio outside `[0.85, 1.15]`, header/`run_meta`
  field-count mismatch, and value/validity-flag contradictions.

---

## 8. Decision log (rubric criterion 4)

- **Async, bounded, drop-oldest** — logging never blocks or grows unbounded;
  under I/O pressure the robot keeps driving and the loss is measured.
- **Evidence, not conclusions** — every tier-2 value is a function of the raw
  inputs plus the config; the missing-value convention keeps "not measured"
  distinct from "measured zero".
- **Per-run provenance** — `run_meta.json` makes a log attributable to an exact
  build and config, so a plot from two weeks ago is still interpretable.
- **Raw + shaped signals together** — makes control/tuning data-driven.
- **Geometry logged in every mode** — walls and segments are no longer
  NORMAL-only, so corners and direction search are debuggable too.

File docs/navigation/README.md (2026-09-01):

# Navigation

The decision-making core of the robot. It consumes processed LiDAR (walls,
obstacles) plus the OTOS heading/speed, and produces a `NavigationCommand`
(target speed, steering angle, target acceleration) for the actuator layer.

**Source code:** [`code/modules/navigation`](../../../../code/modules/navigation)
· State machine: [`navigation_controller.cpp`](../../../../code/modules/navigation/navigation_controller.cpp) / [`.hpp`](../../../../code/modules/navigation/navigation_controller.hpp)
· State types: [`navigation_state.hpp`](../../../../code/modules/navigation/navigation_state.hpp)
· Direction search: [`init_direction.cpp`](../../../../code/modules/navigation/init_direction.cpp)
· Learned map: [`track_map.cpp`](../../../../code/modules/navigation/track_map.cpp)

---

## 1. State machine

The controller is a four-state machine (`NavigationMode` in
`navigation_state.hpp`):

```
        ┌──────────────────┐
        │ SEARCH_DIRECTION │  centre in corridor, decide CW vs CCW
        └────────┬─────────┘
                 │ direction confirmed (init_direction)
                 ▼
        ┌──────────────────┐   front wall within trigger distance
        │      NORMAL       │ ─────────────────────────────┐
        │ wall-follow       │◀───────────────┐             │
        └────────┬─────────┘   turn complete │             ▼
                 │                            │      ┌────────────┐
                 │                            └──────│  TURNING   │
                 │                                   │ 90° corner │
                 │  turn_count == total_turns (12)   └────────────┘
                 ▼
        ┌──────────────────┐
        │     FINISHED      │  stop
        └──────────────────┘
```

`NavigationController::update()` dispatches to `update_search_direction()`,
`update_normal()`, or `update_turning()` each tick, then runs the result
through `condition_command()` (output shaping) before returning.

---

## 2. SEARCH_DIRECTION — deciding CW vs CCW

The driving direction is randomised each round, so the robot must infer it.
While unknown, the robot drives slowly (`search_speed_mps = 0.25`) and centres
itself between the side walls (`search_center_kp = 0.8`).

`InitialDirectionEstimator` ([`init_direction.cpp`](../../../../code/modules/navigation/init_direction.cpp))
decides the direction from LiDAR geometry:

- For each side (left = would-turn-LEFT, right = would-turn-RIGHT) it checks
  whether that side wall **continues forward** or is **cut off by a
  perpendicular wall** — the open side is the direction the track turns.
- Evidence is scored across several geometric tests (side-wall validity,
  forward continuation, a connecting perpendicular wall, front-wall support)
  and **confirmed over multiple frames** (`required_confirm_frames = 3`,
  `score_decay = 0.7`) so a single noisy scan cannot flip the decision.
- Once confirmed, the direction is locked and the machine moves to NORMAL.

Key thresholds (`InitialDirectionConfig`): collinearity `≤ 8°` / `0.04 m`,
continuation gap `≤ 0.20 m`, perpendicular tolerance `≤ 15°`, minimum candidate
length `0.15 m`.

---

## 3. NORMAL — wall following

The robot follows the **outer** wall at a target lateral distance
(`target_outer_distance_m = 0.30`). `resolve_track_walls()` maps the LiDAR
left/right walls to inner/outer using the known driving direction.

Steering comes from a **Stanley controller** (see [Control](../control/README.md)):

- `calculate_cross_track_error()` — lateral offset from the target line to the
  outer wall.
- `calculate_wall_heading_error()` — angle between the wall and the robot.

These feed `StanleyController::calculate(cross_track, heading_error, speed, dt)`,
which combines a heading term with a speed-scaled cross-track term.

**Lost-wall fallback.** If the outer wall momentarily disappears (e.g. at a
corner mouth), the controller holds the last valid wall heading for up to
`max_heading_hold_s = 0.30 s`; longer losses fall back to
`lost_wall_speed_mps = 0.25` with zero steering, rather than steering on stale
data.

Cruise speed in NORMAL is `normal_speed_mps = 0.85`.

---

## 4. Turn triggering

`should_start_turn()` fires when the front wall is within an **effective**
trigger distance that grows with speed to compensate for perception + steering
latency:

```
effective_trigger = turn_trigger_distance_m + speed · turn_preview_time_s
                    (base 0.50 m)                    (0.08 s)
```

The trigger must hold for `turn_trigger_confirm_frames = 2` consecutive frames
before the machine commits to TURNING. As the front wall approaches, speed is
ramped down from `approach_speed_mps = 0.72` toward the corner speed.

---

## 5. TURNING — geometric corner trajectory

Rather than snapping to the final 90° heading (which saturates the steering and
cuts the corner), the controller tracks a **moving heading reference** that
sweeps smoothly through the corner:

- **Ackermann feed-forward.** A constant-radius arc (`corner_radius_m = 0.40`,
  `wheelbase_m = 0.18`) gives the nominal steering angle
  `δ_ff = atan(wheelbase / radius)`; the corner radius comes from the WRO outer
  corner geometry (0.10 m wall radius, path 0.30 m inside → ≈0.40 m).
- **Entry/exit blending.** `smoothstep` blends the steering in over
  `turn_entry_blend_rad = 10°` and out over `turn_exit_blend_rad = 22°`, so the
  command has no steps.
- **Heading PID correction.** `turn_heading_pid` corrects the vehicle heading
  onto the moving reference, on top of the feed-forward.
- **Corner speed limit.** `calculate_corner_speed_mps()` caps speed at
  `sqrt(max_lateral_acceleration · radius)` with
  `max_lateral_acceleration_mps2 = 1.40` (raise only after grip testing on the
  real surface). Base turning speed is `turning_speed_mps = 0.65`.

A turn is complete when the heading error is within
`heading_tolerance_rad = 5°` for `heading_confirm_frames = 3` frames; the turn
count increments and the machine returns to NORMAL. After
`total_turns = 12` (three laps × four corners) it goes to FINISHED.

Heading conventions (OTOS): `+heading = CCW`; a CW turn is `−90°`, a CCW turn is
`+90°`; `heading_to_steering_sign = −1` maps heading error to the steering
convention (`− = LEFT`, `+ = RIGHT`).

---

## 6. Command conditioning (output shaping)

`condition_command()` removes jitter and enforces actuator limits before the
command leaves the controller:

- steering low-pass filter (`steering_filter_time_constant_s = 0.035`) and slew
  limit (`max_steering_rate_rad_s = 7.0`);
- speed converted to an acceleration request by `speed_pid`, bounded by
  `max_acceleration_mps2 = 1.8` / `max_deceleration_mps2 = 3.0`;
- `dt` is derived from timestamps and clamped to
  `[min_update_period_s, max_update_period_s] = [0.005, 0.12]` so a stalled
  frame cannot produce a huge integral or derivative kick.

---

## 7. Track map — learn on lap 1, replay on laps 2–3

`TrackMap` ([`track_map.cpp`](../../../../code/modules/navigation/track_map.cpp))
records each corner's entry/exit pose, preferred trigger distance, radius, and
safe speed as **`CornerLandmark`s** (four corners, `TRACK_CORNER_COUNT = 4`),
blended across observations with an EMA (`update_weight = 0.25`).

On later laps, `replay_hint(pose, next_corner_index)` returns a `ReplayHint`
(distance to the next corner entry, preferred trigger/radius/safe speed,
confidence) when confidence ≥ `minimum_replay_confidence = 0.60` and the robot
is within `replay_preview_distance_m = 1.10 m` and roughly aligned
(`replay_max_heading_error_rad = 0.45`). This lets the controller start slowing
and setting up for a corner *before* it can see the wall, which is more stable
than reacting purely live.

The hint is computed in the Open Challenge app loop **before** `update()` and
passed into it in the same tick (see `code/app/_challenge/open/main.cpp`), so
the map preview and the control step stay in sync.

> Traffic-light landmarks (`TrafficLandmark`, `observe_traffic_light`) exist in
> `TrackMap` for the Obstacle Challenge but are **not yet wired into the Open
> Challenge loops**.

---

## 8. Entry points (Open Challenge)

The Open Challenge run program uses the shared controller
([`code/app/_challenge/open`](../../../../code/app/_challenge/open)):

| Program | Behaviour |
|---|---|
| `open_challenge_main` | **Lap 1 learns** the track map, **laps 2–3 replay** it, SPI active |

It wires perception → navigation → actuator (`spi_master`) and logs telemetry.

---

## 9. Decision log (rubric criterion 4)

Visible in the code:

- **Geometric corner + feed-forward instead of "steer to 90°"** — avoids
  steering saturation and corner-cutting; the moving reference keeps the corner
  smooth and repeatable.
- **Speed-scaled turn trigger and lateral-acceleration speed cap** — the corner
  is entered at a physically safe speed instead of a fixed guess.
- **Learn-then-replay track map** — a three-lap event gives few observations, so
  the map is a conservative EMA that lets later laps anticipate corners while
  live wall-following still runs underneath.
- **Command conditioning as a single stage** — one place enforces smoothness and
  actuator limits, so individual state handlers stay simple.
- **Multi-frame confirmation** for both direction search and turn completion —
  robustness against single-scan noise.

The source tree contains controller constants and a deterministic corner
simulation, but it does not contain a real-track measurement log, tuning report,
state-machine image, or an obstacle-challenge controller. These items must be
added from the team's hardware tests before claiming measured performance.

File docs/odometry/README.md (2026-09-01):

# Odometry System (OTOS)

Provides short-term pose estimation — position and heading — from a SparkFun
**Optical Tracking Odometry Sensor (OTOS, PAA5160E1)**. This is the motion
reference the control layer uses to hold a heading and to estimate how far the
car has traveled between LiDAR/camera updates.

**Source code:** [`code/modules/otos`](../../../../code/modules/otos)
· Device wrapper: [`otos.cpp`](../../../../code/modules/otos/otos.cpp) /
[`otos.hpp`](../../../../code/modules/otos/otos.hpp)
· Linux I²C backend: [`linux_i2c.cpp`](../../../../code/modules/otos/linux_i2c.cpp) /
[`linux_i2c.hpp`](../../../../code/modules/otos/linux_i2c.hpp)

---

## 1. Why an optical odometry sensor

The OTOS is a self-contained optical-flow + IMU module that reports fused
`x, y, heading` directly, instead of the robot having to integrate wheel
encoders and a separate gyro itself. On a steered (Ackermann-style) car, wheel
odometry alone is noisy because of tire slip and steering geometry; an optical
ground-tracking sensor sidesteps wheel slip entirely.

---

## 2. Architecture

The code reuses SparkFun's cross-platform **SparkFun Toolkit** driver
(`sfDevOTOS`) and only supplies the two platform-specific pieces the toolkit
needs on a Raspberry Pi:

- **`otos::OTOS`** (extends `sfDevOTOS`) — provides the `delayMs()` the driver
  requires (implemented with `std::this_thread::sleep_for`) and an
  `initialize(bus_num)` convenience method.
- **`LinuxI2C`** (extends `sfTkII2C`) — implements the toolkit's I²C interface
  on top of the Linux `/dev/i2c-*` character device (`open`, `ioctl(I2C_SLAVE)`,
  `read`/`write`, register read/write, `ping`).

This is the standard way to port a SparkFun Arduino-style driver to Linux: keep
the device logic from the vendor, replace only the bus and timing shims.

---

## 3. Initialization sequence

From `OTOS::initialize()`:

1. `bus_.openBus(bus_num)` — open the Linux I²C bus.
2. `bus_.setAddress(kDefaultAddress)` — select the OTOS default address.
3. `sfDevOTOS::begin(&bus_)` — hand the bus to the vendor driver; abort on
   error.
4. Set units to the values the rest of the code expects:
   - **linear unit = meters**
   - **angular unit = radians**

Using meters + radians here keeps the odometry in the same units as the LiDAR
(meters) and the camera bearing (radians), so no unit conversion is needed when
the data is fused.

---

## 4. Integration notes

- The module is compiled as part of the main build
  ([`code/modules/otos/CMakeLists.txt`](../../../../code/modules/otos/CMakeLists.txt))
  and depends on the SparkFun Toolkit and OTOS SDK vendored under
  [`code/external`](../../../../code/external).
- Because units are set to meters/radians at init, the pose it returns can be
  consumed directly by the (future) control loop for heading hold and distance
  tracking.

---

## 5. Decision log (rubric criterion 4)

Already visible in the code:

- **OTOS over raw wheel encoders + gyro** — one fused optical pose output,
  immune to wheel slip, less integration code to get wrong.
- **Reusing the SparkFun Toolkit** — only the I²C/timing shims are custom, so the
  well-tested device logic is inherited rather than reimplemented.
- **Meters + radians at init** — matches LiDAR and camera units so fusion needs
  no conversions.

The Linux wrapper uses the bus number passed to `OTOS::initialize()`; the
current default is bus 1. Physical wiring, mounting height, calibration
scalars, and measured drift are hardware-test records and are not present in
this source snapshot. The pose is consumed by navigation when a valid pose is
available; the Open Challenge loop uses it for map preview and telemetry.

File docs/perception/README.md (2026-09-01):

# Perception (Sensor Fusion)

Associates camera detections with LiDAR obstacle clusters so each obstacle
carries both a **geometric position** (from LiDAR) and a **colour / required
pass side** (from the camera). It also forwards the resolved track walls and the
parking wall, and maps obstacles into world coordinates when a pose is
available.

**Source code:** [`code/modules/perception`](../../../../code/modules/perception)
· [`perception.cpp`](../../../../code/modules/perception/perception.cpp) / [`perception.hpp`](../../../../code/modules/perception/perception.hpp)

---

## 1. Why fuse

- **LiDAR** gives accurate distance/position and width, but no colour — it
  cannot tell a red marker from a green one.
- **Camera** gives colour and a bearing, but poor distance.

The Obstacle Challenge rule is colour-dependent (pass red on one side, green on
the other), so a marker's position *and* colour must be known together. Fusion
attaches the camera colour to the LiDAR geometry.

---

## 2. Pipeline (`Perception::process`)

Inputs: `ProcessedLidarData`, `ProcessedCameraData`, and an optional vehicle
`MapPose`.

1. **Time sync gate** — a camera frame is only fused with a LiDAR scan when
   their timestamps differ by ≤ `max_sensor_time_difference_us = 100 ms`.
2. **Sanity gates** — reject NaN/Inf and out-of-range LiDAR points
   (`minimum_lidar_distance_m = 0.05`, `maximum_lidar_distance_m = 3.00`) and
   invalid camera objects, on top of the processors' own filters.
3. **Frame transform** — each LiDAR obstacle is moved from the LiDAR mount frame
   into the robot frame using `SensorMount{right_m, forward_m, yaw_rad}`.
4. **Bearing association** — for each LiDAR obstacle a **predicted camera
   bearing** is computed from its robot-frame position (via the camera mount)
   and compared to each camera object's `bearing_rad`. A pair is accepted only
   if the bearing error is within
   `max_bearing_difference_rad = 8°`.
5. **Confidence** — a `fusion_confidence` is formed from the bearing agreement;
   a pair is `frame_confirmed` only if it clears
   `minimum_confirmed_confidence = 0.55`.
6. **Colour → side** — a confirmed camera colour is mapped to
   `TrafficColor{RED,GREEN}` and a `PassSide{LEFT,RIGHT}`.

Output is `PerceptionData`: track walls, optional parking wall, a list of
`FusedObstacle`, the indices of unmatched camera detections, and a
`PerceptionDiagnostics` block.

---

## 3. `FusedObstacle` (what downstream gets)

Each obstacle reports its source (`LIDAR_ONLY` or `LIDAR_CAMERA_FUSED`),
robot-frame position, optional world position, distance, width, LiDAR bearing,
and — when fused — camera colour, `traffic_color`, `required_pass_side`, the
predicted-vs-measured bearing error, and the fusion confidence.

> **Important semantics (from the header):** `frame_confirmed` means the camera
> and LiDAR agreed **in this one frame**. It is *not* temporal tracking — a
> caller should still require the same obstacle to be confirmed over several
> frames before committing it as a map landmark. LiDAR-only obstacles are kept
> in the output (never silently dropped) but are never marked confirmed.

---

## 4. Diagnostics

`PerceptionDiagnostics` exposes counts at every stage (LiDAR input/valid/
rejected, camera input/valid/rejected, matched, frame-confirmed, unmatched on
each side) plus the timestamps and whether the pose and camera time were valid.
This is what makes the `test_perception` tool able to explain *why* an object
was or wasn't fused, instead of just showing the result.

---

## 5. Decision log (rubric criterion 4)

Visible in the code:

- **Predicted-bearing association** — projecting the LiDAR obstacle into the
  camera's expected bearing and matching against detections is robust to the
  camera's weak range, and needs only the mount geometry, not a full extrinsic
  calibration.
- **Frame-confirmed ≠ tracked** — the module is explicit that a single-frame
  match is not proof of a stable object, pushing temporal confirmation to the
  caller where lap context lives.
- **Keep unmatched detections** — unmatched LiDAR and camera objects stay in the
  output for debugging rather than being discarded.

The fusion code uses `lidar_mount` and `camera_mount` values from
`PerceptionConfig`; the current source keeps the defaults in
`code/modules/perception/perception.hpp` and does not provide a measured mount
survey. `FusedObstacle` is produced for downstream obstacle handling, but the
current Open Challenge navigation controller consumes LiDAR walls rather than
the fused obstacle list. No measured fusion-accuracy result is stored in the
repository.

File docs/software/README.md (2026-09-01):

# Software Architecture

How the code is organized, how the pieces run concurrently, and how it is built
and deployed to the robot.

**Source tree:** [`code/`](../../../../code)

---

## 1. Layered structure

The system is written in **C++17** and organised into hardware modules,
stateless processors, decision/control layers, and applications:

```
code/
├── common/         direction.hpp (DrivingDirection, TurnDirection)
│
├── modules/        Hardware ownership + I/O (stateful, threaded) and processing
│   ├── camera/     CameraModule → frames ; CameraProcessor → objects
│   ├── lidar/      LidarModule  → scans  ; LidarProcessor  → walls/obstacles
│   ├── otos/       OTOS + LinuxI2C → pose
│   ├── perception/ Perception → fuse camera + LiDAR (+ pose) → FusedObstacle
│   ├── navigation/ NavigationController (state machine), init_direction, track_map
│   ├── spi/        SPI master → STM32 (motor/servo/battery)
│   └── logging/    AsyncCsvWriter, telemetry/wall loggers (Logger V1)
│
├── control/        PID, StanleyController (used by navigation)
│
├── app/
│   ├── _challenge/open/   open_challenge_main (learn+replay) + actuator
│   ├── test_camera, test_lidar, test_perception, test_otos, test_spi
│   └── adjust_HSV, adjust_white, camera_tuner
│
├── external/       Vendored SDKs (LCCV, rplidar_sdk, OTOS, SparkFunToolkit) — submodules
├── utils/          RingBuffer.hpp
├── CMakeLists.txt
├── Dockerfile.compile / Dockerfile.cross
└── build_n_deploy.sh
```

The guiding rule: **modules touch hardware and hold state; processors are pure
functions.** A processor (camera, lidar, perception) takes timestamped inputs
and returns a structured result with no side effects, which makes it testable on
recorded data. The navigation controller holds the run state machine; the
control layer holds reusable PID/Stanley primitives.

For the full end-to-end signal flow diagram, see the
[documentation index](../README.md).

---

## 2. Concurrency model

Each sensor module runs its own **capture/scan thread** so that acquisition is
never blocked by processing:

- The thread pushes each new sample into a fixed-size
  [`RingBuffer<T, N>`](../../../../code/utils/RingBuffer.hpp) (camera N=30, lidar
  N=10) under a mutex.
- A `condition_variable` plus a monotonically increasing **sequence counter**
  lets a consumer:
  - `get_latest()` — take the newest sample without blocking, or
  - `wait_for_frame()` / `wait_for_data()` — block until a genuinely new sample
    arrives (the sequence counter guarantees the same sample is not processed
    twice).

`RingBuffer` itself is intentionally **not** internally synchronized — the owning
module holds the mutex. This keeps the buffer a simple, allocation-free
`std::array` and puts locking in one place.

Every sample carries a `steady_clock` **timestamp in microseconds**, captured at
acquisition time, so camera and LiDAR results can be aligned in time by the
fusion/navigation layer.

---

## 3. Data types (contracts between layers)

| Type | Produced by | Consumed by |
|---|---|---|
| `TimedFrameData` | CameraModule | CameraProcessor |
| `ProcessedCameraData` (color, bbox, bearing) | CameraProcessor | Perception |
| `TimedLidarData` (polar points) | LidarModule | LidarProcessor |
| `ProcessedLidarData` (segments, walls, parking wall, obstacles) | LidarProcessor | Perception, Navigation |
| OTOS pose (x, y, heading), speed | OTOS | Navigation |
| `PerceptionData` (walls, `FusedObstacle[]`) | Perception | Navigation (obstacle challenge) |
| `NavigationCommand` (speed, steering, accel) | NavigationController | Actuator |
| `ReplayHint` | TrackMap | NavigationController |
| SPI `Command` frames | Actuator / SPI master | STM32 |
| `TelemetryRow` / `WallRow` / `CornerRow` | app loop | logging (CSV) |

---

## 4. Build system

- **CMake ≥ 3.10**, `CMAKE_CXX_STANDARD 17`.
- The top-level [`code/CMakeLists.txt`](../../../../code/CMakeLists.txt) finds OpenCV
  and libcamera, then adds the module and app subdirectories.
- Dependencies: **OpenCV** (vision + geometry math), **libcamera/LCCV**
  (camera), **rplidar_sdk** (LiDAR), **SparkFun Toolkit + OTOS SDK** (odometry).

### Cross-compilation with Docker

The robot runs on a **Raspberry Pi 5 (arm64)**, but building on the Pi is slow.
The project cross-compiles inside a Docker image instead:

- [`Dockerfile.cross`](../../../../code/Dockerfile.cross) — the arm64 cross toolchain.
- [`Dockerfile.compile`](../../../../code/Dockerfile.compile) — native compile image.

---

## 5. Deployment (`build_n_deploy.sh`)

[`build_n_deploy.sh`](../../../../code/build_n_deploy.sh) automates the
build-and-ship loop:

| Command | Action |
|---|---|
| `./build_n_deploy.sh` | Incremental cross-build (Ninja + ccache) then deploy |
| `./build_n_deploy.sh clean` | Remove build/install artifacts |
| `./build_n_deploy.sh clean-all` | Also clear the ccache |
| `./build_n_deploy.sh cross` | Rebuild the cross-compiler Docker image |

Pipeline:

1. Ensure the `cross-pi` Docker image exists (build it if missing).
2. Run CMake + Ninja **inside the container**, with `ccache` for fast
   incremental rebuilds, installing to a local `dist/install`.
3. `rsync` the install tree to the Pi over SSH
   (`PI_USER@PI_IP:PI_TARGET_DIR`), deleting stale files.

> The Pi's user/IP/target directory are set at the top of the script and must be
> updated for your own robot before first deploy.

---

## 6. Current status & roadmap

**Implemented today (full Open Challenge loop):**

- sensor acquisition — camera, LiDAR, OTOS;
- processing — camera object detection, LiDAR wall/obstacle/parking resolution;
- **[perception](../perception/README.md)** — camera↔LiDAR fusion with colour;
- **[navigation](../navigation/README.md)** — four-state machine, CW/CCW
  direction search, geometric corner trajectory with Ackermann feed-forward,
  Stanley wall following, command conditioning;
- **[control](../control/README.md)** — reusable PID + Stanley;
- **[track map](../navigation/README.md#7-track-map--learn-on-lap-1-replay-on-laps-23)** —
  learn on lap 1, replay on laps 2–3;
- **[SPI](../spi/README.md)** actuation to the STM32, with a fail-safe actuator;
- **[logging](../logging/README.md)** — async CSV telemetry (Logger V1);
- one Open Challenge run program (`open_challenge_main`, learn+replay) and a
  full set of test/calibration tools;
- the full cross-compile + deploy pipeline.

**Still open (main gaps for the Obstacle Challenge):**

- **obstacle avoidance is not yet wired into `navigation_controller::update()`**
  — perception already outputs coloured, positioned obstacles, but the
  controller does not yet act on them;
- **parallel parking** manoeuvre;
- traffic-light landmarks exist in `TrackMap` but are not used by the loops yet.

The current Open Challenge executable does not yet consume fused coloured
obstacles for avoidance and does not implement parallel parking. Those are
separate Obstacle Challenge work items, not behaviours provided by the current
executable.

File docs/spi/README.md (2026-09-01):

# SPI Link (RPi ↔ STM32)

The Raspberry Pi 5 is the high-level brain; a separate **STM32** microcontroller
drives the motors and steering servo and reads the battery. They communicate
over **SPI**, with the Pi as master. This document describes the master side.

**Source code:** [`code/modules/spi`](../../../../code/modules/spi)
· [`spi_master.cpp`](../../../../code/modules/spi/spi_master.cpp) / [`spi_master.hpp`](../../../../code/modules/spi/spi_master.hpp)

---

## 1. Why a split controller

Real-time actuation (PWM for the servo, motor duty/encoder loops) is better done
on a dedicated MCU with deterministic timing than on Linux, which is not
real-time. The Pi runs perception and navigation; the STM32 executes the
low-level motor/servo commands the Pi sends. SPI gives a fast, simple
master/slave link between them.

---

## 2. Bus configuration

`SPI::initialize()` opens a Linux `spidev` device with:

| Parameter | Default |
|---|---|
| Chip select | 0 |
| Mode | `SPI_MODE_0` |
| Bits per word | 8 |
| Speed | 15 MHz |

---

## 3. Frame format

Every transfer is a fixed **3-byte frame**: one `Command` byte + a 16-bit data
field. Signed values (e.g. motor power) are encoded as 16-bit two's complement
in the data field; responses are decoded with `decode_data()`.

---

## 4. Command set (`spi::Command`)

| Group | Commands |
|---|---|
| Test / debug | `NULL_ (0x00)`, `ECTO_TEST (0x01)`, `DEBUG (0xFF)` |
| Motor control | `M_ENABLE/M_DISABLE`, `M1_POW/M2_POW`, `M1_DUTY/M2_DUTY` |
| Motor encoder | `M1_SPD/M2_SPD`, `M_Brake`, `M_ENC_ENABLE/DISABLE/INVERTED` |
| Servo | `SERVO_PULSE (0x40)`, `SERVO_ANGLE (0x41)` |
| Power | `VOL_CHECK (0xA0)` |

Public API (from `spi_master.hpp`):

- `echo_test(value, response)` — link sanity check.
- `enable_motors()` / `disable_motors()`.
- `set_motor_power(Motor, percent)` — signed −100…+100.
- `set_motor_speed(Motor, percent)` — 0…100.
- `set_servo_pulse_us(pulse_us)` — 1000…2100 µs.
- `set_servo_angle(angle_deg)` — 0…180°, centre 90°.
- `read_voltage_v()` — battery voltage (controller returns unsigned mV).

---

## 5. How navigation reaches the motors

The Open Challenge actuator layer
([`open_challenge_actuator.hpp`](../../../../code/app/_challenge/open/open_challenge_actuator.hpp))
converts a `NavigationCommand` into SPI calls:

- `target_speed_mps` → percent of `full_scale_speed_mps` (0.85) → `set_motor_power(M1, …)`.
- `steering_rad` → servo pulse in `[1000, 2100] µs` (centre ≈ 1550) →
  `set_servo_pulse_us(…)`.

It also arms/disarms and performs an **emergency stop** (motor power 0) on
destruction or any SPI failure — a safety-first default.

---

## 6. Decision log (rubric criterion 2 & 4)

Visible in the code:

- **Two-controller split** — deterministic actuation on the STM32, heavy compute
  on the Pi; SPI is the fast link between them.
- **Fixed 3-byte framing** — trivial to implement identically on both sides and
  cheap to parse on the MCU.
- **Fail-safe actuator** — any SPI error or object destruction forces motor
  power to zero, so a comms glitch cannot leave the car driving.

This repository documents the Raspberry Pi master only. STM32 timer/PWM
channels, encoder wiring, and the physical MOSI/MISO/SCLK/CS pinout are not
recorded in the source tree and must be taken from the STM32 firmware and the
assembled wiring before publication.

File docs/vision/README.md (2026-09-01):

# Vision System

Detects and classifies the red and green traffic markers used in the Obstacle
Challenge, and reports each detection's position and relative bearing to the
navigation layer.

**Source code:** [`code/modules/camera`](../../../../code/modules/camera)
· Capture: [`camera_module.cpp`](../../../../code/modules/camera/camera_module.cpp)
· Processing: [`camera_processor.cpp`](../../../../code/modules/camera/camera_processor.cpp)
· Shared types: [`camera_struct.hpp`](../../../../code/modules/camera/camera_struct.hpp)

---

## 1. Responsibilities

The vision subsystem is split into two independent concerns:

- **`CameraModule`** — owns the camera hardware and runs a background capture
  thread. It never processes pixels; it only produces timestamped frames.
- **`CameraProcessor`** — a stateless pipeline that turns one frame into a list
  of detected objects. Because it holds no state, it is trivial to unit-test and
  to run on recorded frames offline.

This separation means the capture rate and the processing rate are decoupled:
the newest frame is always available, and the processor consumes frames when it
is ready rather than blocking the camera.

---

## 2. Capture pipeline (`CameraModule`)

The camera is a Raspberry Pi Camera Module 3, accessed through
**libcamera** via the **LCCV** wrapper (`lccv::PiCamera`).

Default configuration (constructor defaults in `camera_module.hpp`):

| Parameter | Default | Notes |
|---|---|---|
| `video_width` | 640 px | Square capture (see below) |
| `video_height` | 640 px | |
| `framerate` | 90 fps | Capture target |
| `awb_gain_r` | 1.4 | Manual red white-balance gain |
| `awb_gain_b` | 2.6 | Manual blue white-balance gain |

Key design points, all present in `camera_module.cpp`:

- **Dedicated capture thread.** `start()` launches `capture_loop()` on its own
  thread. Continuous autofocus is enabled once at start
  (`AfMode = AfModeContinuous`).
- **180° rotation.** Every frame is flipped on both axes (`cv::flip(frame,
  frame, -1)`) to compensate for the camera being mounted upside-down on the
  chassis.
- **Ring buffer, newest-wins.** Frames are pushed into a
  `RingBuffer<TimedFrameData, 30>`. Consumers call either:
  - `get_latest()` — non-blocking, returns the most recent frame, or
  - `wait_for_frame()` — blocks until a *new* frame arrives (uses a
    `condition_variable` and a frame-sequence counter so the same frame is never
    processed twice).
- **Timestamping.** Each frame is tagged with a `steady_clock` timestamp in
  microseconds at capture time, so downstream fusion can align camera and LiDAR
  data in time.

> **Manual white balance is deliberate.** Auto white balance shifts the hue of
> the red/green markers as lighting changes, which would break the fixed HSV
> thresholds below. Fixing `awb_gain_r`/`awb_gain_b` keeps marker colors stable.
> The tuning tools in [`code/app/adjust_white`](../../../../code/app/adjust_white) and
> [`code/app/adjust_HSV`](../../../../code/app/adjust_HSV) exist to find these values
> for a given venue.

---

## 3. Processing pipeline (`CameraProcessor`)

```
Frame (BGR)
   │
   ▼  cvtColor BGR → HSV
HSV image
   │
   ▼  inRange (red ×2 ranges, green ×1)
Binary masks (red, green)
   │
   ▼  morphology OPEN then CLOSE (4×4 rect kernel)
Cleaned masks
   │
   ▼  findContours (external only)
Contours
   │
   ▼  geometric validation (area / size / aspect / fill)
Valid objects
   │
   ▼  bottom-center + bearing estimation
ProcessedCameraData (list of CameraObject)
```

### 3.1 Color thresholds (HSV)

Defined in `camera_processor.hpp`. Red spans two ranges because its hue wraps
around the 0°/180° boundary of the OpenCV hue circle:

| Color | Lower HSV | Upper HSV |
|---|---|---|
| Red (range 1) | (0, 70, 50) | (10, 255, 255) |
| Red (range 2) | (170, 70, 50) | (179, 255, 255) |
| Green | (50, 95, 60) | (85, 200, 200) |

The two red masks are OR-ed together into a single red mask.

### 3.2 Morphological filtering

A single 4×4 rectangular kernel is applied as **OPEN** (remove small
noise specks) followed by **CLOSE** (fill small holes inside a marker), to each
color mask independently.

### 3.3 Contour validation

Contours are extracted with `RETR_EXTERNAL` (outer boundaries only). Each
candidate must pass **all** of the following filters (constants in
`camera_processor.hpp`) to be accepted as a marker:

| Filter | Condition | Value |
|---|---|---|
| Minimum area | `contourArea ≥` | 650 px² |
| Minimum width | `bbox.width ≥` | 15 px |
| Minimum height | `bbox.height ≥` | 25 px |
| Aspect ratio | `min ≤ w/h ≤ max` | 0.5 … 1.5 |
| Fill ratio | `area / (w·h) ≥` | 0.7 |

The aspect-ratio and fill-ratio checks together reject elongated or hollow
shapes (walls, reflections, floor lines), keeping roughly rectangular, solid
blobs — which is what an upright marker looks like from the car.

### 3.4 Object output

For every valid contour a `CameraObject` is produced with:

- `color` — `Red` or `Green`
- `bounding_box` — the pixel-space rectangle
- `bottom_center` — `(x + w/2, y + h)`, i.e. the mid-point of the bottom edge.
  The **bottom** edge is used (not the centroid) because that is where the
  marker meets the floor, which is the most stable reference for estimating how
  far ahead the marker is.
- `bearing_rad` — see below.

### 3.5 Bearing estimation

The horizontal bearing to a marker is computed from a pinhole-camera model
using the bottom-center x-coordinate:

```
bearing = atan( (pixel_x − cx) / fx )
```

with intrinsic parameters (in `camera_processor.hpp`):

| Parameter | Value | Meaning |
|---|---|---|
| `fx` | 1268.97425 | Focal length in pixels (x) |
| `cx` | 317.980325 | Principal point x (≈ image center for 640 px) |

A positive bearing means the marker is to the right of the optical axis, a
negative bearing means to the left. This single scalar is what the navigation
layer needs to decide which side to pass a marker on.

---

## 4. Development & calibration tools

These live in [`code/app`](../../../../code/app) and share the same modules:

| Tool | Purpose |
|---|---|
| [`test_camera`](../../../../code/app/test_camera) | Capture and save frames; validate the module end-to-end |
| [`adjust_HSV`](../../../../code/app/adjust_HSV) | Interactively tune the red/green HSV thresholds |
| [`adjust_white`](../../../../code/app/adjust_white) | Tune the manual white-balance gains |
| [`camera_tuner`](../../../../code/app/camera_tuner) | General camera-parameter tuning |

---

## 5. Decision log (rubric criterion 4)

Decisions that are already visible in the code:

- **BGR→HSV before thresholding** — HSV separates hue from brightness, so a
  single hue band tolerates lighting changes far better than an RGB box.
- **Two red ranges** — required by the hue wrap-around; a single range cannot
  capture red.
- **Bottom-center as the reference point** — most stable ground contact for
  distance/bearing, versus a centroid that moves as the marker is partially
  occluded.
- **Fixed white balance** — trades auto-adaptability for color stability, which
  the fixed HSV thresholds depend on.

The current calibration values are the constants in
`code/modules/camera/camera_processor.hpp`: `fx = 1418.29334` and
`cx = 973.219296`, documented for the 1920×1080 capture geometry. The
repository does not include the calibration procedure, a labelled test set,
measured detection accuracy, or a failure log. The 90 fps / 640×640 capture
configuration is the current `CameraModule` default and should be retained
only after confirming that the deployed camera mode and processing budget match
the hardware.

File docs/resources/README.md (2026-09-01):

# docs/resources

This directory is reserved for photographs, wiring diagrams, state-machine
figures, and CAD renders referenced by the documentation. No binary resource
files are included in the current source snapshot; links are added only when
the corresponding files are committed.

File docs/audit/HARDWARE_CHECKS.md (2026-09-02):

# Hardware checks — frame conventions and mount results

The audit found two disagreements between code and documentation. Check 1 is
now resolved from the assembled robot and datasheet convention; Check 2 still
needs a short physical test before changing any world-frame transform.

Check 1 (M-1) has now been resolved from the assembled-robot observation below.
Check 2 remains open until the OTOS world-axis push test is performed.

---

## Check 1 — LiDAR raw angle zero (F-07)

**The disagreement.** `LidarProcessor::polar2cartesian`
(`code/modules/lidar/lidar_processor.cpp:135-143`) computes:

```cpp
result.x_m = point.distance_m * -std::sin(rad);
result.y_m = point.distance_m * -std::cos(rad);
```

Both `mark.txt` and `docs/lidar/README.md` specify the same formula **without
the minus signs**. The code is therefore a 180° rotation of the documented
mapping — at `angle_deg = 0` the documented formula puts a point at `y = +d`
(ahead) and the code puts it at `y = −d` (behind).

Either the sensor is mounted with its raw-zero axis pointing backwards and the
negation is a correct, undocumented compensation, or it is a genuine bug. The
source cannot tell which.

### Procedure

1. Put the robot on the floor with a flat wall roughly **1 m directly in front**
   of it, and nothing within 2 m on the other three sides.
2. Find the RPLIDAR's own raw-angle-zero reference (the silkscreen mark or the
   cable exit — check the S3 datasheet for which one marks 0°) and note which
   way it points relative to the robot's forward direction.
3. Run the LiDAR viewer:
   ```bash
   ./test_lidar
   ```
4. On the rendered view, find the drawn robot origin and the fitted wall.

### Result (M-1 — recorded)

The raw-zero arrow points to the **rear of the robot**. Therefore the physical
front is raw 180°. With the current code's two minus signs, raw 180° maps to
`(x, y) = (0, +distance)`, so the robot frame remains **+Y forward**. The
forward translation term in deskew (`dy = v * dt`) has the correct sign.

**Result:** PASS — P-22 may enable deskew; do not change `polar2cartesian()`.
The minus signs are the documented 180° mount compensation.
**Date / who ran it:** recorded from team/datasheet confirmation, 2026-09-02

---

## Check 2 — OTOS world axis at heading 0 (F-08)

**The disagreement.** Two robot→world transforms read the same OTOS pose in the
same process and differ by a constant 90°:

| Implementation | At heading 0 |
|---|---|
| `perception::robot_to_world` (`perception.cpp:231-246`) | forward → **+world X**, right → −world Y |
| `NavigationController::update_wall_corner_landmark` (`navigation_controller.cpp:~734`) | forward → **+world Y**, right → +world X |

`obstacle_controller.hpp::to_robot` is the exact algebraic inverse of the
`perception` version, so two of three already agree and the navigation one is
the outlier. That is strong evidence but not proof — this check establishes
which convention the physical sensor actually reports.

### Procedure

1. Place the robot on the floor pointing along whichever direction the team
   calls "forward" on the field diagram. Note that direction.
2. Power up and let `calibrate_otos()` finish (keep the robot **completely
   still** during calibration — it calls `calibrateImu(255, true)` then
   `resetTracking()`, so this defines the zero).
3. Run any app that prints the pose — `./test_otos` is simplest.
4. Confirm the reported heading is near **0 rad**. If it is not, the tracking
   reset did not take; restart before continuing.
5. **Push the robot straight forward by hand** about 1 m along the direction
   from step 1. Do not let it rotate.
6. Read the reported `x` and `y`.

### What to record

- [ ] `x` grew by ~1.0 m and `y` stayed near 0 → **forward is +world X.**
      `perception::robot_to_world` is correct; the navigation wall-corner
      transform is the one to fix.
- [ ] `y` grew by ~1.0 m and `x` stayed near 0 → **forward is +world Y.**
      The navigation transform is correct; `perception::robot_to_world` and
      `obstacle_controller::to_robot` both need fixing — note that this is the
      more expensive outcome, since it means the obstacle world positions
      (including the new `obstacle_world_x_m`/`obstacle_world_y_m` telemetry
      columns) are currently 90° wrong.
- [ ] Neither — both changed, or the magnitude is far off 1 m → the OTOS
      mounting offset or scaling is wrong, which is a separate problem. Record
      the raw numbers and stop.

Measured `x` after the 1 m push: `__________`
Measured `y` after the 1 m push: `__________`
Measured heading during the push: `__________`

**Result:** _______________________________________________
**Date / who ran it:** ____________________________________

---

## Why this matters even though nothing is visibly broken

`wall_corner_filtered_world_` is currently only converted back to robot frame by
the same function's own inverse, so the 90° error cancels and today's turn
trigger works. The moment that world position is cross-referenced against
anything built on the `perception` convention — `TrackMap`, the traffic
landmarks, `ObstacleController`'s landmark matching — the error becomes live and
the landmark lands 90° away from the real corner.

Stage 3 of the fix plan brings the obstacle controller and the navigation
controller into the same loop. That is the point at which this stops being
theoretical.

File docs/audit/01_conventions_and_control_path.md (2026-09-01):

# Audit Report 1 — Conventions and Control Path

Scope: drive/steering control path (Subsystem A) as defined in
`docs/AUDIT_PLAN_DRIVE_AND_LOGGING.md`. Working tree at commit `4f9f970` plus
uncommitted changes. Read-only audit; no source files were modified.

---

## 1. Phase A — Convention ledger

| # | Convention | Defined where | Formula as written in code | Consumers | Agrees with ledger? |
|---|---|---|---|---|---|
| 1 | LiDAR raw angle meaning | `mark.txt`, `docs/lidar/README.md` | "0° = front (หน้า), 90° = right (ขวา)" | `LidarProcessor::polar2cartesian` | **NO — see §2.1** |
| 2 | LiDAR polar → robot Cartesian | `LidarProcessor::polar2cartesian` (`code/modules/lidar/lidar_processor.cpp:135-143`) | `x_m = distance_m * -sin(rad); y_m = distance_m * -cos(rad);` where `rad = angle_deg * PI/180` | All of `LidarProcessor` (split/merge, `resolve_track_walls`, `detect_obstacles`, `find_parking_wall`) | **NO** — `mark.txt` and `docs/lidar/README.md` both specify `x = d·sin(angle), y = d·cos(angle)` (no negation). The code's formula is the point-reflection (180°-rotated) of the documented one. See §2.1. |
| 3 | Robot frame axes (`lidar::LineSegment`, `ObstacleObject`) | Implicit from `polar2cartesian` output | `+x_m`/`+y_m` are whatever `polar2cartesian` produces (see row 2) | `resolve_track_walls` (`center.x<0`→left, `center.y>0`→front), `detect_obstacles`, `ObstacleObject::bearing_rad() = atan2(center.x, center.y)` | Internally self-consistent (all LiDAR-side code uses the same, possibly-rotated, frame) but not necessarily aligned with `mark.txt`'s stated "+X=right, +Y=forward" (see §2.1) |
| 4 | `perception::RobotPoint` axes | `perception.hpp:49-52`, comment lines 14-17 | `right_m` = robot-frame right, `forward_m` = robot-frame forward. Comment: "Bearing is positive to the right" | `Perception::lidar_to_robot`, `predicted_camera_bearing`, `ObstacleController::to_robot`/`nearest_observation` | `lidar_to_robot()` maps LiDAR's `cv::Point2f{x,y}` → `RobotPoint{right_m, forward_m}` via `right=x·cos(yaw)+y·sin(yaw)`, `forward = -x·sin(yaw)+y·cos(yaw)` — i.e. it assumes LiDAR's `x` axis **is already** "right" and `y` **is already** "forward" (mount yaw = 0 in both live apps). This assumption is only correct if `polar2cartesian` follows the documented (non-negated) convention. Given row 2, this is a place where a wrong `polar2cartesian` silently propagates: `lidar_to_robot` does not re-derive right/forward from raw angle, it trusts the LiDAR module's `x/y` labels. |
| 5 | Wall line angle | `LidarProcessor::fit_line_segment` (PCA), `resolve_track_walls` | `theta = 0.5*atan2(2*Sxy, Sxx-Syy)`; classification: `|corrected_angle| ≈ 90°` → left/right, `|corrected_angle| ≈ 0°` and `center.y>0` → front | `resolve_track_walls`, `NavigationController::calculate_wall_heading_error`, `has_forward_wall_continuation` | Self-consistent within the (possibly rotated) LiDAR frame from row 2. If row 2's frame is 180°-rotated from the documented one, "front" as classified here corresponds to physical **behind**, not physical front, unless the raw-angle convention itself differs from `mark.txt` at the mount level (see §2.1 discussion — cannot fully resolve without hardware). |
| 6 | Steering sign | `navigation_controller.hpp:121-129` comment; `stanley_controller.hpp:46-48` | "steering < 0 = LEFT, steering > 0 = RIGHT" | `StanleyController::calculate`, `NavigationController::calculate_cross_track_error/calculate_wall_heading_error/calculate_search_steering`, `condition_command`, `ActuatorOutput::to_servo_pulse_us` (`steering_to_servo_sign=1.0`, positive steering → positive `signed_command_deg` → pulse above `servo_center_pulse_us`), `ObstacleController::apply` (`side=+1`→RIGHT) | **Consistent** everywhere it is used within scope — see B1/B2 traces. `heading_to_steering_sign=-1` and `turn_heading_sign_` are the two explicit flips (row 7). |
| 7 | Sign flips of the steering convention | `heading_to_steering_sign` (`navigation_controller.hpp:129`, default `-1`); `turn_heading_sign_` (member, set in `start_turn()`); `steering_to_servo_sign` (`open_challenge_actuator.hpp:26`, `1.0`) | `heading_to_steering_sign` converts OTOS heading-error sign (CCW+) to steering sign; `turn_heading_sign_ = heading_delta>=0 ? +1 : -1` selects which way the moving reference sweeps; `steering_to_servo_sign` is a final pass-through multiplier (`1.0`, i.e. currently a no-op) before the servo pulse map | `update_normal` (lost-wall heading hold), `update_turning` (feedforward + tracking term), `to_servo_pulse_us` | Consistent chain: OTOS heading-error (rad, CCW+) × `heading_to_steering_sign(-1)` → steering convention (+ = RIGHT) × `steering_to_servo_sign(1.0)` → servo command. No contradiction found in this chain. |
| 8 | OTOS heading sign | `navigation_controller.hpp:112-116` comment: "+heading = CCW" | `clockwise_turn_delta_rad = -PI/2`, `counter_clockwise_turn_delta_rad = +PI/2` | `start_turn`, `calculate_turn_heading_error`, `update_normal`'s lost-wall heading hold, `perception::robot_to_world` (comment: "positive heading turns toward +world Y") | **Assumed but never independently verified in software** — this is a hardware fact about the OTOS unit's firmware/mounting; the code is internally consistent with the assumption but nothing in the repository proves the physical sensor actually reports CCW-positive. This is the single hardware measurement needed to settle S4 (see report 02). |
| 9 | Robot → world transform (forward) | Three implementations, compared algebraically below | See §2.2 | `perception::Perception::robot_to_world`, `NavigationController::update_wall_corner_landmark` (forward), `ObstacleController::to_robot` (inverse) | **Two of the three implementations disagree by a 90° rotation** — see §2.2. `CONFIRMED` as S4 in report 02. |
| 10 | Bearing convention | `perception.hpp:14-17` comment: "Bearing is positive to the right" | `ObstacleObject::bearing_rad() = atan2(center.x, center.y)` (lidar_struct); `Perception::predicted_camera_bearing = atan2(relative_right, relative_forward) - camera_yaw` | `Perception::process` bearing-matching loop, camera fusion | Consistent: both use `atan2(right-like, forward-like)`, so positive bearing = to the right, matching the doc comment. Depends on row 2/3 being correct for the LiDAR side. |
| 11 | Units — steering/angle config fields | `navigation_controller.hpp`, `open_challenge_common.hpp` | Correctly-converted fields consistently use `deg * PI / 180.0f` (e.g. `turn_entry_blend_rad`, `turn_exit_blend_rad`, `heading_tolerance_rad`, `wall_corner_collinear_angle_rad`) | All angle-typed `NavigationConfig`/`ObstacleConfig` fields | **One violation found: `exit_acceleration_blend_rad = 20.0f` at `open_challenge_common.hpp:95` has no `* PI / 180.0f`.** `CONFIRMED` as S1 in report 02. |
| 12 | Units — distance/speed fields | Field names carry `_m`, `_mps`, `_mps2`, `_s` suffixes throughout `NavigationConfig`, `ObstacleConfig`, `ActuatorConfig` | — | — | All distance/speed/time fields observed in scope carry a unit suffix in their name. No un-suffixed ambiguous field was found. |
| 13 | `StanleyConfig::max_steering_rad` default-value comment | `stanley_controller.hpp:18` | `float max_steering_rad{0.785398f}; // 30 deg` | Comment only (no functional effect) | **Comment is wrong.** `0.785398 rad = 45.0°`, not 30°. `docs/control/README.md` independently states the default is "30°", inheriting the same stale comment. Minor doc-drift (LOW), noted under duplicated/stale documentation, not a behavioural bug. |

### 2.1 Convention disagreement — LiDAR polar→Cartesian (row 1/2/3)

`code/modules/lidar/lidar_processor.cpp:135-143`:

```cpp
CartesianPoint LidarProcessor::polar2cartesian(const LidarPoint &point) const {
	CartesianPoint result;
	result.distance_m = point.distance_m;
	const float rad = point.angle_deg * static_cast<float>(M_PI) / 180.f;
	result.x_m = point.distance_m * -std::sin(rad);
	result.y_m = point.distance_m * -std::cos(rad);
	return result;
}
```

`/home/jukkruw/iLARP/mark.txt` (the load-bearing convention document named in the
audit plan) states:

```
LiDAR raw angle          Robot Cartesian
0° = หน้า (front)    →    +X = ขวา (right)
90° = ขวา (right)    →    +Y = หน้า (forward)
```

and `docs/lidar/README.md:109-114` independently states the same formula
without negation: `x = distance·sin(angle), y = distance·cos(angle)`.

Evaluating both at `angle_deg = 0` (documented as "front"):
- Documented formula: `x=0, y=+distance` (point ahead, on the +Y/forward axis). Correct.
- Code: `x = -distance·sin(0) = 0`, `y = -distance·cos(0) = -distance` (point placed **behind** the robot).

At `angle_deg = 90` (documented as "right"):
- Documented formula: `x=+distance, y=0` (point to the right).
- Code: `x = -distance·sin(90°) = -distance`, `y = -distance·cos(90°) = 0` (point placed to the **left**).

The code's formula is `(x,y) = -(documented x, documented y)` at every angle —
a 180° rotation (point reflection) of the documented mapping, not merely a
single-axis sign flip. This is internally self-consistent (it is still a valid
right-handed 2-D frame; `resolve_track_walls`, `detect_obstacles`, etc. all
consume the same rotated frame), so it does not necessarily mean the robot
mis-detects walls — **if** the physical LiDAR unit's raw `angle_deg=0` axis is
actually mounted pointing toward the robot's rear (a mounting choice, not a bug),
the negation would be the correct compensation and `mark.txt`/`docs/lidar/README.md`
would be the stale documents.

This cannot be resolved from source alone. It is carried into report 02 as a
confirmed convention *disagreement* between code and both cited documents; the
single test that would settle it is: point the LiDAR's silkscreen/cable-exit
reference mark (raw `angle_deg=0`) at a known wall and confirm in `test_lidar`
whether that wall renders in front of (+Y) or behind (-Y) the drawn robot
origin.

### 2.2 Robot → world transform — three implementations compared (row 9)

**`perception::Perception::robot_to_world`** (`code/modules/perception/perception.cpp:231-246`):

```cpp
world.x = pose.x + forward_m * cos(heading) + right_m * sin(heading);
world.y = pose.y + forward_m * sin(heading) - right_m * cos(heading);
```

Comment at line 237-239: "OTOS/world convention: heading 0 points along +world
X and positive heading turns toward +world Y. Robot-right is therefore
-world Y at heading 0." This is algebraically a proper rotation matrix applied
to the orthonormal basis (forward = +X at heading 0, right = -Y at heading 0):
at `heading=0`, `world = pose + (forward, -right)`, matching the stated
convention exactly.

**`NavigationController::update_wall_corner_landmark`** forward transform
(`code/modules/navigation/navigation_controller.cpp:730-736`):

```cpp
const float cosine = std::cos(map_pose->heading_rad);
const float sine = std::sin(map_pose->heading_rad);
const cv::Point2f candidate_world{
	map_pose->x_m - forward_m * sine + right_m * cosine,
	map_pose->y_m + forward_m * cosine + right_m * sine};
```

i.e. `world.x = pose.x - forward*sin(h) + right*cos(h)`, `world.y = pose.y +
forward*cos(h) + right*sin(h)`. At `heading=0`: `world = pose + (right,
forward)` — **forward maps onto +world Y and right maps onto +world X**, the
opposite axis assignment from `perception::robot_to_world`'s stated convention
(which puts forward on +world X at heading 0). The two formulas differ by a
constant 90° rotation for all headings (verified algebraically by rotating the
`perception` basis vectors `(1,0)` and `(0,-1)` by 90°: `(1,0)→(0,1)`,
`(0,-1)→(1,0)`, which reproduces exactly the `right→+X, forward→+Y` mapping
used in `navigation_controller.cpp`).

The same function's **inverse** (world→robot, used for
`wall_corner_forward_m`/`wall_corner_lateral_m`, lines 798-803):

```cpp
debug.wall_corner_forward_m = -delta_x * sine + delta_y * cosine;
debug.wall_corner_lateral_m = delta_x * cosine + delta_y * sine;
```

is the correct algebraic inverse of its own forward transform above (internally
consistent with itself), so the 90° discrepancy is solely between
`navigation_controller.cpp`'s convention and `perception.cpp`'s convention, not
an internal bug within `navigation_controller.cpp`.

**`obstacle_challenge::ObstacleController::to_robot`**
(`code/app/_challenge/obstacle/obstacle_controller.hpp:232-239`):

```cpp
static RobotPosition to_robot(const Observation &observation, const navigation::MapPose &pose) {
	const float dx = observation.x_m - pose.x_m;
	const float dy = observation.y_m - pose.y_m;
	const float cosine = std::cos(pose.heading_rad);
	const float sine = std::sin(pose.heading_rad);
	return {dx * sine - dy * cosine, dx * cosine + dy * sine};
}
```

Algebraically inverting `perception::robot_to_world`'s formula for
`(forward,right)` given `(dx,dy)=(world-pose)` yields exactly `forward =
dx·cos(h)+dy·sin(h)`, `right = dx·sin(h)-dy·cos(h)` — which is precisely what
`to_robot` computes (`RobotPosition{right_m, forward_m}` = `{dx·sin-dy·cos,
dx·cos+dy·sin}`). **`to_robot` is the exact inverse of `perception::robot_to_world`,
not of `navigation_controller.cpp`'s forward transform.**

**Conclusion:** two of the three implementations in scope
(`perception::robot_to_world` and `obstacle_controller.hpp::to_robot`) agree
with each other; `navigation_controller.cpp`'s wall-corner-landmark transform
is the outlier, rotated 90° from the other two. This is strong internal
evidence (not proof) that the wall-corner-landmark transform is the wrong one,
but confirming which convention matches the *physical* OTOS output still
needs hardware: drive the robot in a straight line with heading held at 0 and
confirm the world X/Y the OTOS reports moves along the axis the team calls
"forward" on the field diagram. Full detail and severity carried to report 02
as **S4 — CONFIRMED (convention mismatch), NEEDS HARDWARE (which is physically correct)**.

---

## 2. Phase B1 — Three end-to-end traces

### B1.a — NORMAL mode, one loop iteration

1. **LiDAR scan arrives** (`lidar.wait_for_data(scan)` in `open/main.cpp:139`).
2. **OTOS pose read** (`otos.getPosVelAcc`) → `heading_rad`, `speed_mps =
   hypot(velocity.x, velocity.y)`.
3. **Wall-heading correction angle** computed:
   `wall_correction_rad = normalize_angle(heading_rad - state.target_heading_rad)`
   (`open/main.cpp:188-189`).
4. **`LidarProcessor::process(scan, wall_correction_rad, 4, 0.035, 0.12, 5.0, 0.04, 0.10)`**
   (`open_challenge_common.hpp:127-131`, `process_scan`) — produces
   `ProcessedLidarData{line_segments, walls{left,right,front}, obstacles,
   parking_wall}`. Internally: `polar2cartesian` → split/merge → PCA fit
   (`fit_line_segment`) → `merge_aligned_segments` → `resolve_track_walls`
   (heading-corrected by `wall_correction_rad`) → `detect_obstacles`.
5. **`NavigationController::update(processed, heading_rad, speed_mps,
   replay_hint, map_pose)`** (`navigation_controller.cpp:16`):
   a. `dt_s = calculate_dt_s(scan.timestamp_us)` — clamped to
      `[min_update_period_s, max_update_period_s] = [0.005, 0.12]` s.
   b. Mode is `NORMAL` → `update_normal(...)`:
      - `resolve_track_walls(lidar_data.walls)` maps left/right → inner/outer
        by `state_.direction` (CW: outer=LEFT, inner=RIGHT; CCW: outer=RIGHT,
        inner=LEFT).
      - Rearm check: if `!state_.turn_armed` and (no front wall, or front wall
        `> turn_rearm_distance_m`) → re-arm and zero `turn_trigger_frames_`.
      - **`should_start_turn(...)`** evaluated every iteration (see B5); if it
        returns `false` (usual case mid-straight), continue.
      - If `track_walls.outer == nullptr` → lost-wall branch (`stanley_.reset()`,
        speed forced to `lost_wall_speed_mps`, steering from heading-hold or 0)
        — **returns early**, skipping the Stanley/speed-profile code below.
      - Otherwise: `cross_track_error_m` from
        `calculate_center_cross_track_error` (corridor-center mode, both walls
        seen) or `calculate_cross_track_error` (outer-only). `heading_error_rad`
        similarly averaged or outer-only.
      - **`command.steering_rad = stanley_.calculate(cross_track_error_m,
        heading_error_rad, speed_mps, dt_s)`** — inside `StanleyController::calculate`
        (`stanley_controller.cpp:8-23`): `cross_track_term =
        atan2(k·cross_track_error_m, speed+softening_speed_mps)`;
        `heading_term = heading_pid_.calculate(0, -heading_error_rad, dt_s)`
        (a full PID, `mutable`, called even though the method is `const`);
        `steering = heading_term + cross_track_term`, clamped to
        `±config_.stanley.max_steering_rad` (38° in the open-challenge config).
      - `command.target_speed_mps = calculate_active_normal_speed_mps()`
        (base `normal_speed_mps`, or replay-factor-scaled on laps ≥2 if
        `enable_replay_speed_factors`); reduced toward
        `calculate_approach_speed_mps(...)` if the wall-corner landmark is
        confirmed and near, or if the front wall is inside
        `approach_distance_m`; further capped by the learned-map preview
        blend if `replay_hint->approach_recommended`.
   c. Back in `update()`: `result.debug.raw_steering_rad =
      result.command.steering_rad` (pre-conditioning snapshot), similarly for
      `raw_target_speed_mps`.
   d. **`condition_command(result.command, speed_mps, dt_s, stop_immediately=false)`**
      (`navigation_controller.cpp:1104-1161`):
      - Speed: rate-limited toward `requested_speed_mps` by
        `max_acceleration_mps2`/`max_deceleration_mps2` × `dt_s` →
        `conditioned_speed_mps_`.
      - Steering: `clamp_steering()` first (±38°), then a first-order
        low-pass filter (`time_constant_s = steering_filter_time_constant_s`,
        `filter_weight = dt/(tc+dt)`), then a slew-rate clamp
        (`max_steering_rate_rad_s × dt_s`), then `clamp_steering()` again →
        `conditioned_steering_rad_`.
      - `acceleration_mps2 = speed_pid_.calculate(conditioned_speed_mps_,
        actual_speed_mps, dt_s)` — **computed but see B6/S8: never actuated.**
      - Returns `{conditioned_speed_mps_, conditioned_steering_rad_,
        acceleration_mps2}`.
6. **`ActuatorOutput::apply(result.command, wheel_rpm_override)`**
   (`open_challenge_actuator.hpp:79-105`):
   - `target_servo_pulse_us = to_servo_pulse_us(command.steering_rad)`:
     convert rad→deg, clamp to `±maximum_steering_command_deg` (45°), apply
     `steering_to_servo_sign` (1.0, no-op), map linearly onto
     `[servo_min_pulse_us, servo_max_pulse_us] = [950, 2000]` around
     `servo_center_pulse_us = 1475`.
   - `servo_pulse_us = limit_servo_pulse_step(target_servo_pulse_us)` — clamps
     the **per-call** pulse delta to `±maximum_servo_step_us = 500 µs`
     (a second, independent rate limiter beyond `max_steering_rate_rad_s`).
   - `wheel_rpm = to_wheel_rpm(command.target_speed_mps)` (open-loop m/s→RPM
     via `wheel_diameter_m`, clamped to `±maximum_wheel_rpm`), unless
     `wheel_rpm_override` is set (search-launch boost).
   - `bus_.set_servo_pulse_us(servo_pulse_us)` → SPI `Command::SERVO_PULSE`
     (3-byte frame). `bus_.set_motor_speed(M1/M2, wheel_rpm)` → SPI
     `Command::M1_SPD`/`M2_SPD` — the **closed-loop** RPM command consumed by
     the STM32's own encoder loop (see B6).
7. **Final integer written to the bus:** a 3-byte SPI frame `{command_byte,
   data_hi, data_lo}` for the servo pulse (`std::uint16_t` µs, e.g. `1475` at
   dead-ahead) and a second 3-byte frame for each motor's signed RPM
   (`std::int16_t`, two's-complement).

### B1.b — TURNING mode, one loop iteration

Entered via `start_turn(heading_rad)` (called from inside `update_normal` when
`should_start_turn()` is true) then immediately falls through to
`update_turning()` in the same tick (`navigation_controller.cpp:209-215`).

1. `start_turn()`: advances `state_.target_heading_rad` by
   `±90°` (`clockwise_turn_delta_rad`/`counter_clockwise_turn_delta_rad`),
   computes `signed_turn_angle_rad` from the *cardinal target*, not the raw
   instantaneous OTOS heading (comment: avoids accumulating a few degrees of
   error per corner). Resets `turn_heading_pid_`, the wall-corner tracker,
   `lost_wall_timer_s_`; **does not reset `stanley_`** (see S13). Sets
   `turn_entry_steering_rad_ = conditioned_steering_rad_` (continuity with the
   last commanded steering). Sets `state_.mode = TURNING`.
2. `update_turning(heading_rad, speed_mps, dt_s, debug)`
   (`navigation_controller.cpp:362-486`):
   - `radius_m = max(0.05, corner_radius_m)` (0.12 m in open config).
   - `corner_speed_mps = calculate_corner_speed_mps()` =
     `min(turning_speed_mps, sqrt(max_lateral_acceleration_mps2 · radius_m))`.
   - Moving reference: `turn_reference_progress_rad_ += min(remaining,
     reference_speed_mps/radius_m · dt_s)` — an angular-rate model driven by
     *measured* speed clamped to `corner_speed_mps`.
   - `heading_error_rad = normalize_angle(state_.target_heading_rad -
     heading_rad)` (OTOS convention). `tracking_error_rad =
     normalize_angle(turn_reference_heading_rad_ - heading_rad)`.
   - Entry/exit blend weights via `smoothstep(progress/blend_rad)` using
     `turn_entry_blend_rad` (22.5°) and `turn_exit_blend_rad` (32°).
   - `feedforward_rad = heading_to_steering_sign · turn_heading_sign_ ·
     atan2(max(0.01,wheelbase_m), radius_m) · min(entry_weight, exit_weight)`
     — **magnitude atan2(0.16375, 0.12) = 53.8° before any blending/clamp**
     (see S9 in report 02).
   - `entry_steering_rad = turn_entry_steering_rad_ · (1 - entry_weight)` —
     continuity term that decays away as the entry blend completes.
   - `tracking_steering_rad = turn_heading_pid_.calculate(0, -tracking_error_rad,
     dt_s) · heading_to_steering_sign`.
   - `command.steering_rad = clamp_steering(entry_steering_rad + feedforward_rad
     + tracking_steering_rad)` — clamp to ±38° (open config).
   - Speed: `exit_acceleration_weight = 1 - smoothstep(|heading_error_rad| /
     exit_acceleration_blend_rad)`; `command.target_speed_mps = corner_speed_mps
     + (active_normal_speed_mps - corner_speed_mps) · exit_acceleration_weight`
     — **with the current mis-set `exit_acceleration_blend_rad=20.0` (raw
     radians, not 20°), this weight is ≈1 for the entire turn, not just near
     exit; see S1.**
   - `is_turn_complete(heading_error_rad)`: true when
     (`reference_complete` and `heading_confirm_frames` streak reached) OR
     (`turn_heading_sign_·heading_error_rad ≤ 0` and reference progressed
     ≥80%) — i.e. the machine can also exit by "crossing" the target even
     without formal confirmation frames. On completion: `++turn_count`,
     `corner_index/lap` recomputed, mode→`NORMAL` (or `FINISHED` at
     `total_turns=12`), `state_.turn_armed=false` to block immediate
     re-trigger from the old corner's wall.
3. `condition_command(...)` runs identically to B1.a (steering filter + slew
   limit + clamp, speed ramp, unused `speed_pid_` output).
4. Same actuator path as B1.a to the final SPI frames.

### B1.c — Obstacle-avoidance path (`code/app/_challenge/obstacle/main.cpp`)

1. LiDAR scan, OTOS pose read (same as B1.a).
2. `processed_lidar = process_scan(...)` (LiDAR pipeline, same as B1.a).
3. Camera frame processed if available; `fused =
   perception.process(processed_lidar, processed_camera, pose)` — LiDAR/camera
   fusion, bearing association, `frame_confirmed` flags.
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

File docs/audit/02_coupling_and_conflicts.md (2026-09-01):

# Audit Report 2 — Coupling, Conflicts, and Findings

Depends on `docs/audit/01_conventions_and_control_path.md` (convention ledger,
B1 traces, B2/B3 tables). Read-only audit; no source files were modified.

---

## 1. Findings (most severe first)

### F-01 — `exit_acceleration_blend_rad` unit bug defeats the corner speed cap

- **Severity:** CRITICAL
- **Status:** CONFIRMED (= S1)
- **Location:** `code/app/_challenge/open/open_challenge_common.hpp:95`; compare
  `code/modules/navigation/navigation_controller.hpp:98` (default) and
  `code/modules/navigation/navigation_controller.cpp:442-446` (consumer)
- **What the code does:** The default is
  `exit_acceleration_blend_rad{15.0f * PI / 180.0f}` (≈0.262 rad), and every
  neighbouring blend field in the same override function is written the same
  way (`turn_entry_blend_rad = 22.5f * PI/180.0f`, `turn_exit_blend_rad = 32.0f
  * PI/180.0f`, `heading_tolerance_rad = 16.50f * PI/180.0f`). The override is
  `config.exit_acceleration_blend_rad = 20.0f;` — a bare `20.0f`, i.e. **20
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

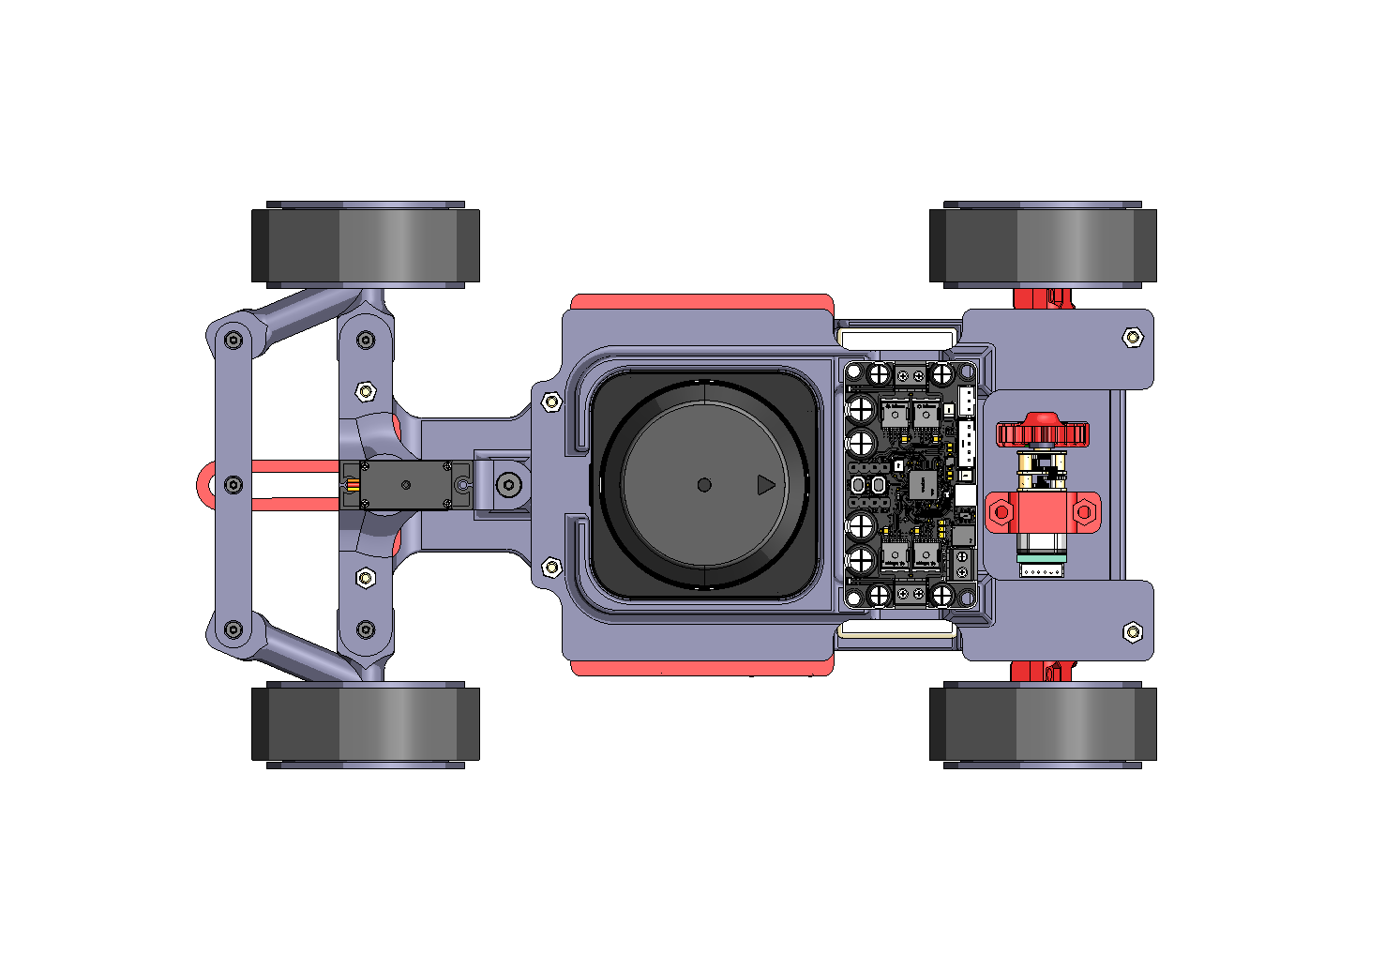
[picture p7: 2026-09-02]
CAD/ASM___main__view_Top.PNG

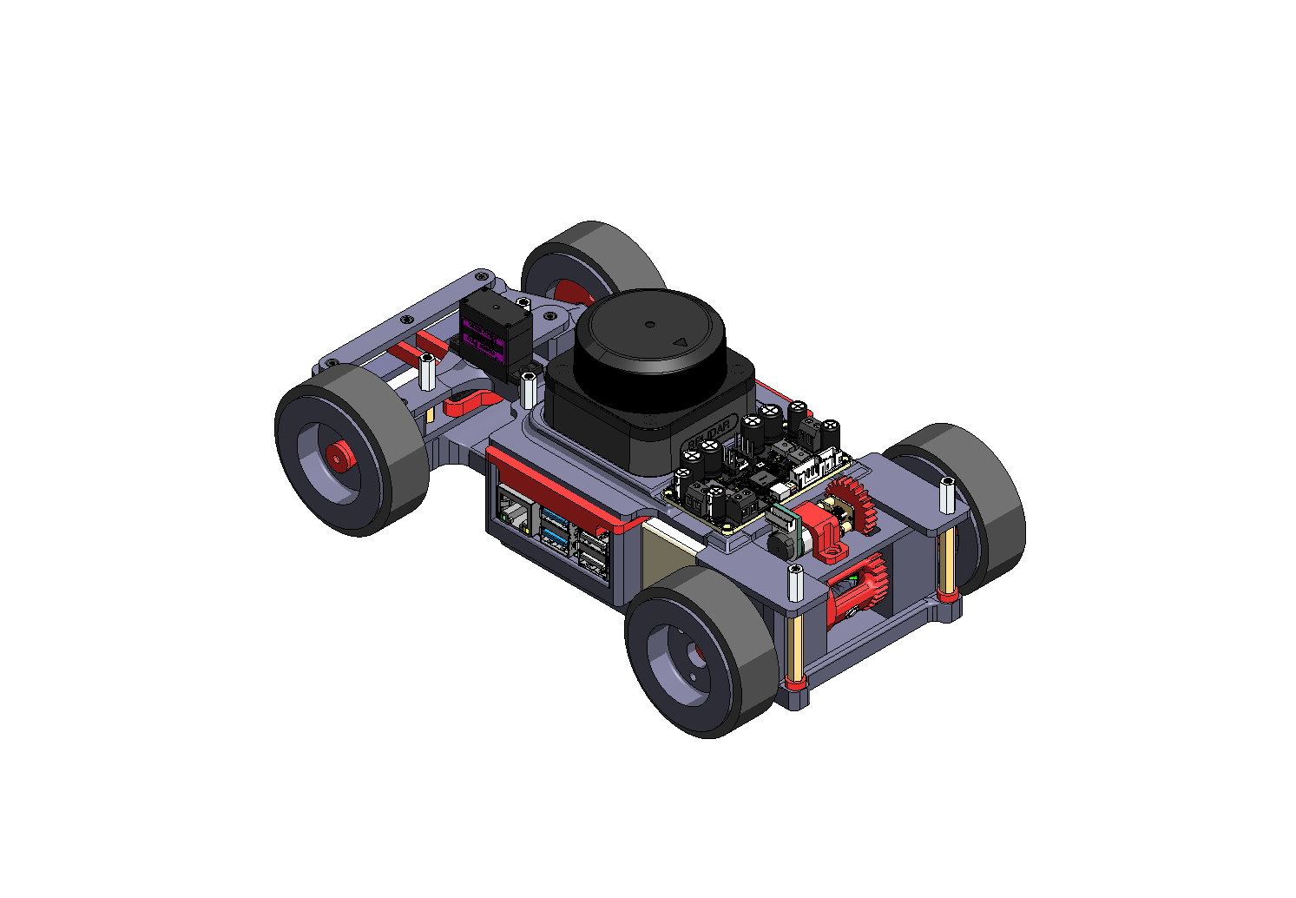
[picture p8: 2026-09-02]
CAD/ASM___main__view_ISOMETRIC.PNG

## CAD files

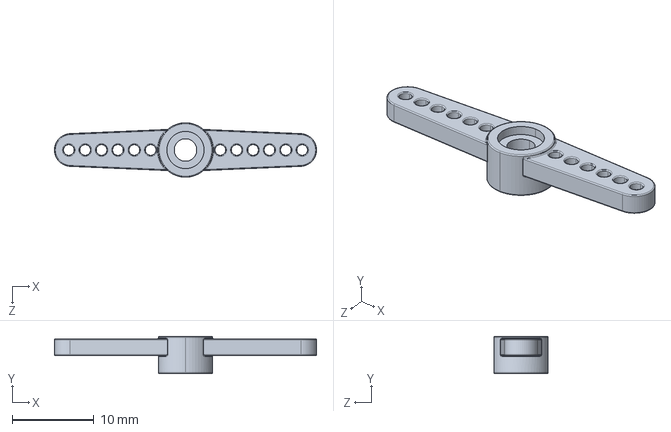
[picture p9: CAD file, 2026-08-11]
CAD/MG90/Shoulder_BiDirectional.STEP
32.0 x 4.55 x 6.65 mm

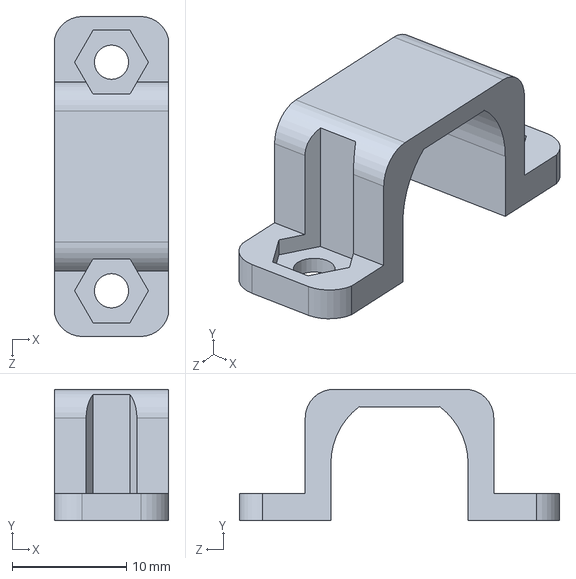
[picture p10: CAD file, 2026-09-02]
CAD/MotorLock_N20_20mm.SLDPRT
10.0 x 11.5 x 28.0 mm

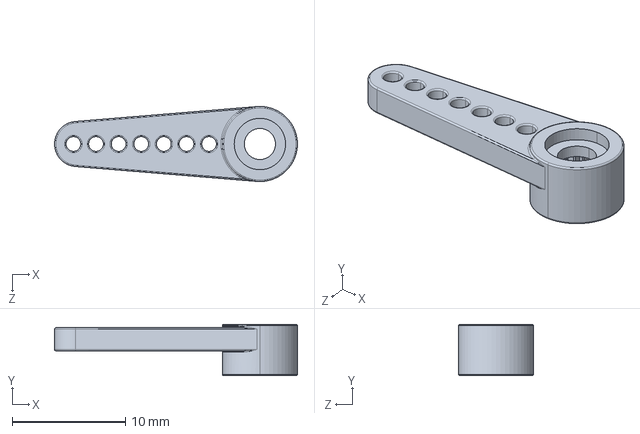
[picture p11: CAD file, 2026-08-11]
CAD/MG90/ShoulderUnidirectional.STEP
21.5 x 4.55 x 6.65 mm

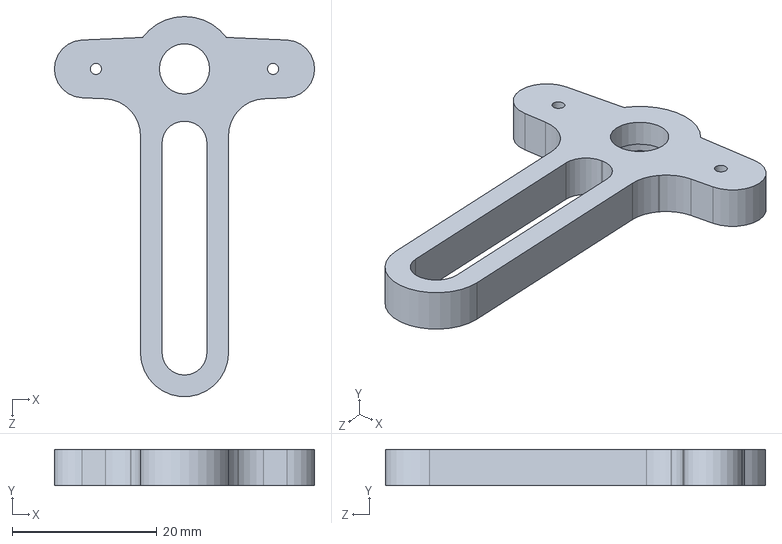
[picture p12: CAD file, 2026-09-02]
CAD/Steering__Shoulder_BiDirectional_case.SLDPRT
36.0 x 5.00 x 52.6 mm

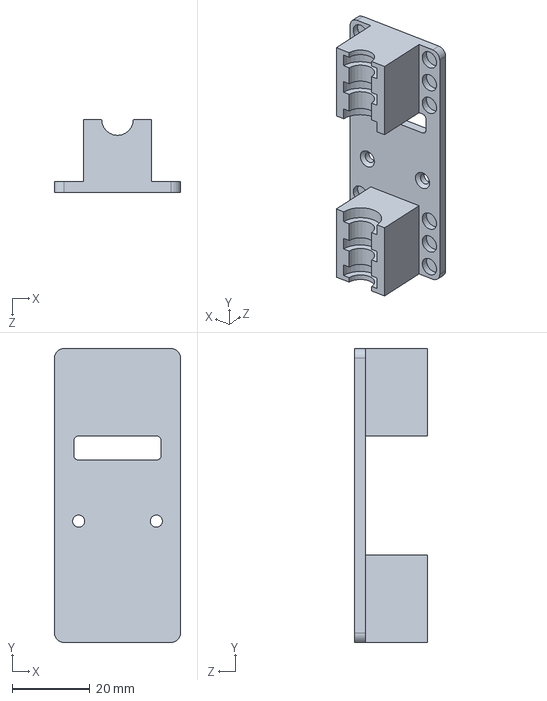
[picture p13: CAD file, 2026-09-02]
CAD/Differential_Holder_cap.SLDPRT
32.5 x 75.7 x 18.8 mm

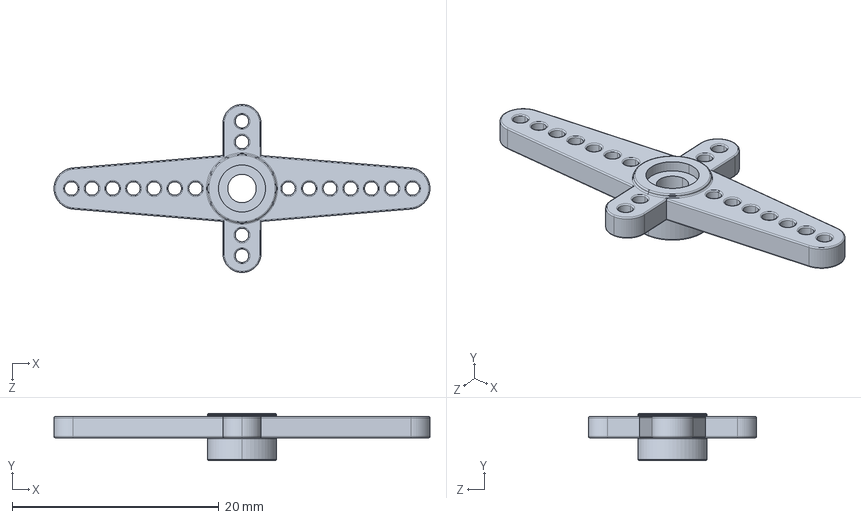
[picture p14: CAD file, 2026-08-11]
CAD/MG90/Shoulder_FourDirected.STEP
36.3 x 4.55 x 16.2 mm

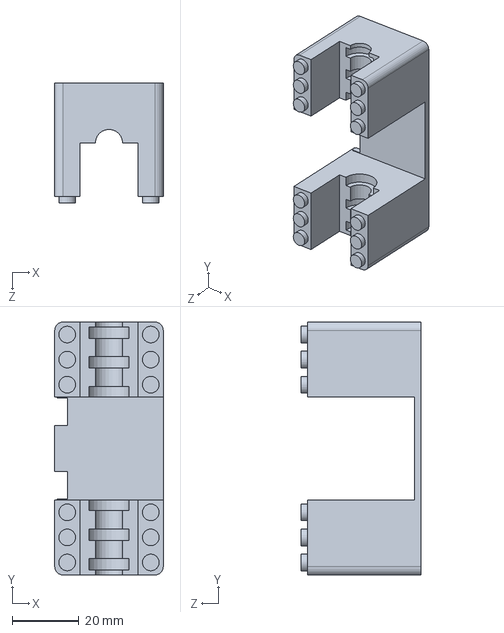
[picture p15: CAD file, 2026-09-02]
CAD/Differential_Holder.SLDPRT
32.5 x 75.7 x 36.0 mm

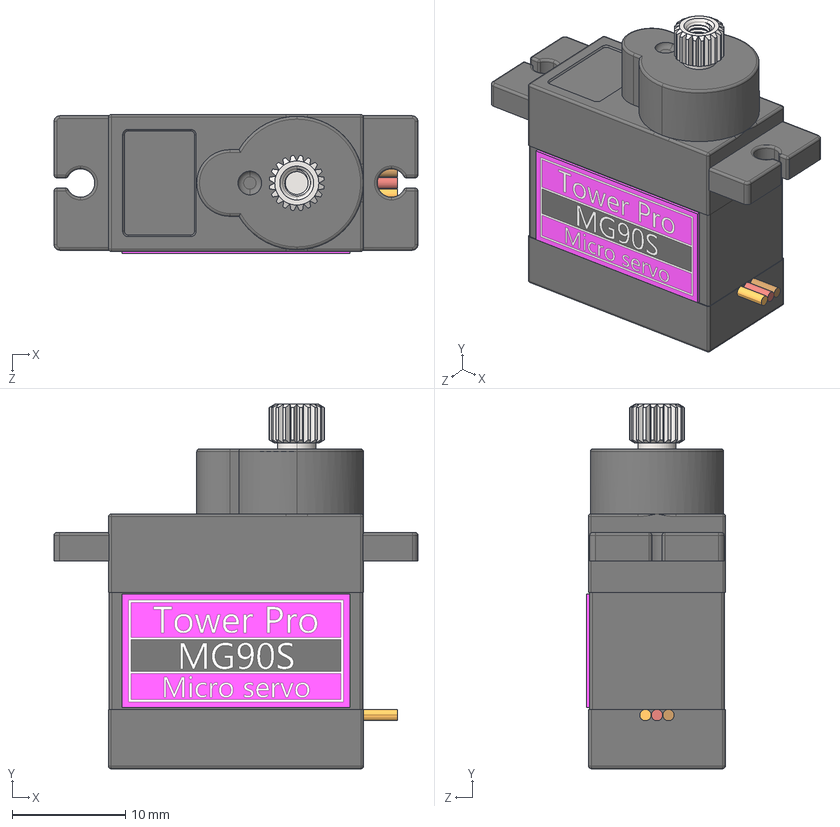
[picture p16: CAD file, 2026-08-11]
CAD/MG90/MG90S_Servo.STEP
32.2 x 32.2 x 12.3 mm

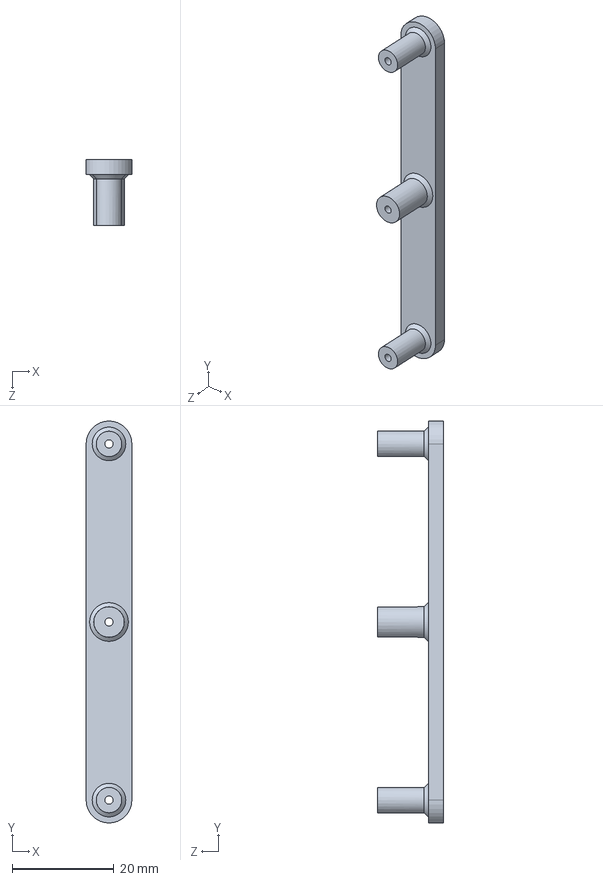
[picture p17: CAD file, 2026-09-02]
CAD/Steering__S_frame.SLDPRT
9.00 x 79.0 x 13.0 mm

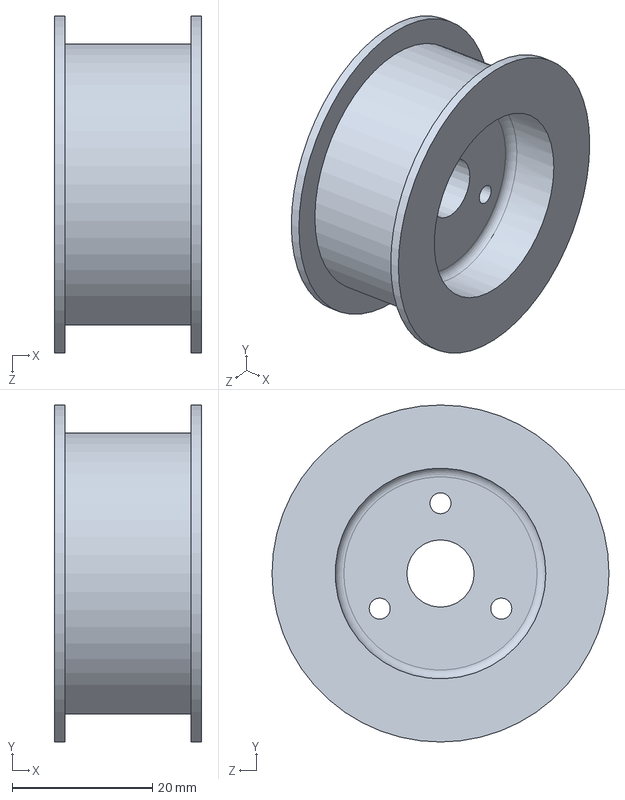
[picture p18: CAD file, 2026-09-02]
CAD/Steering__wheels.SLDPRT
21.0 x 48.0 x 48.0 mm

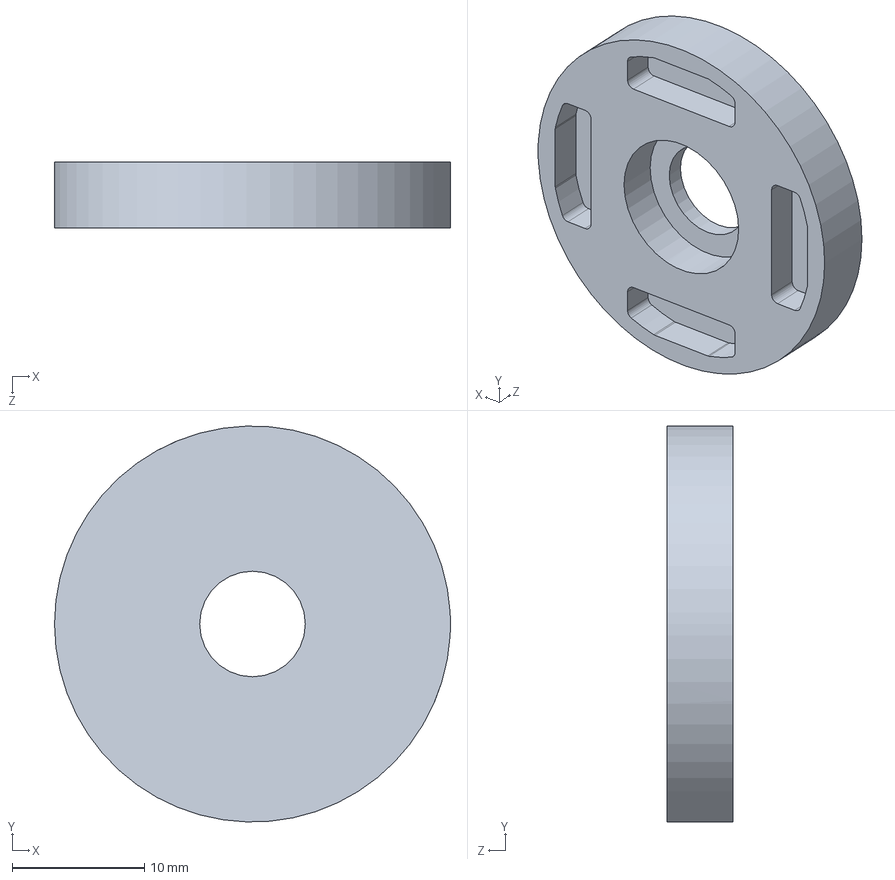
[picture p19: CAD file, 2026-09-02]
CAD/CarrierGear_B___Closer.SLDPRT
30.0 x 30.0 x 5.00 mm

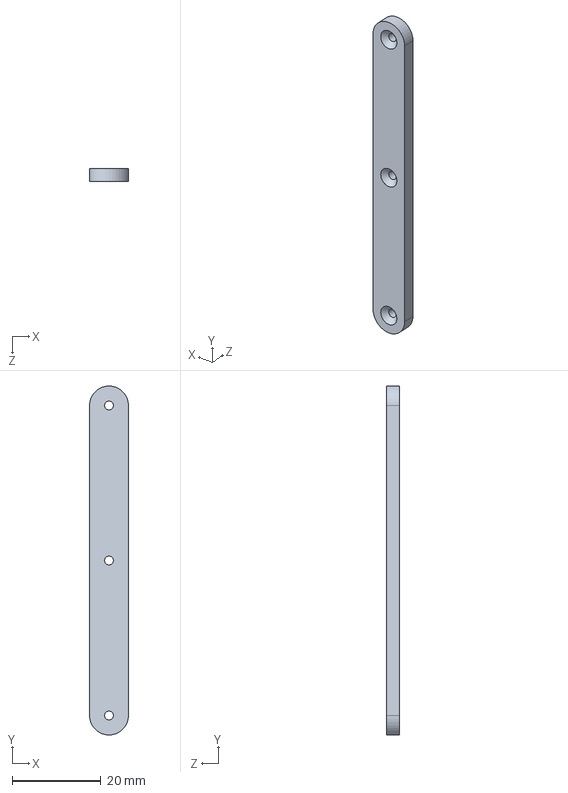
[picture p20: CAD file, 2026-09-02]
CAD/Steering__S_frameTop.SLDPRT
8.80 x 78.8 x 3.00 mm

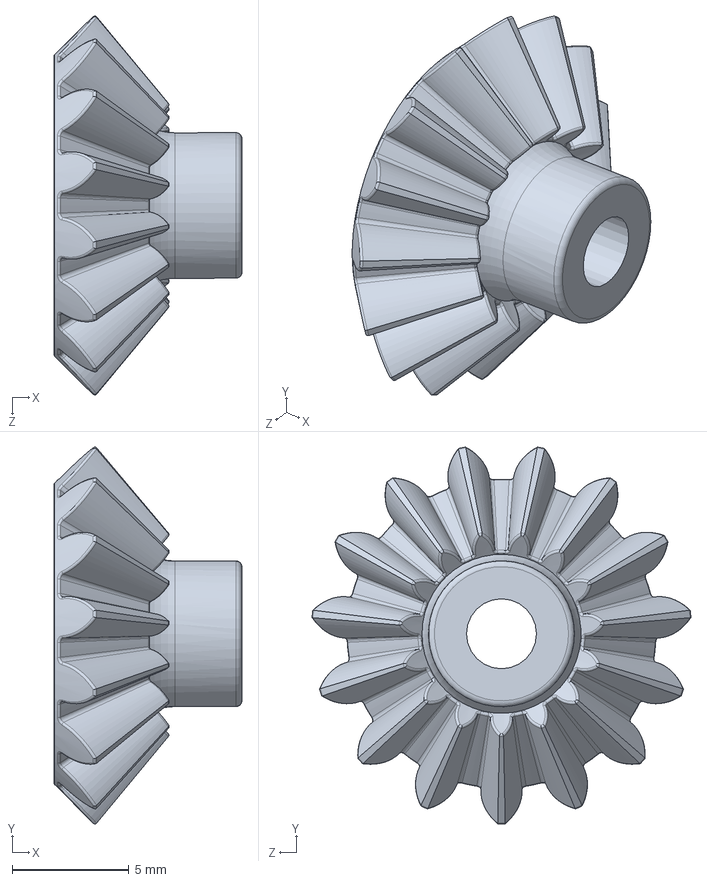
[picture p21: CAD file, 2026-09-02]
CAD/DifferentialGear__Pinions.SLDPRT
8.06 x 16.2 x 16.3 mm

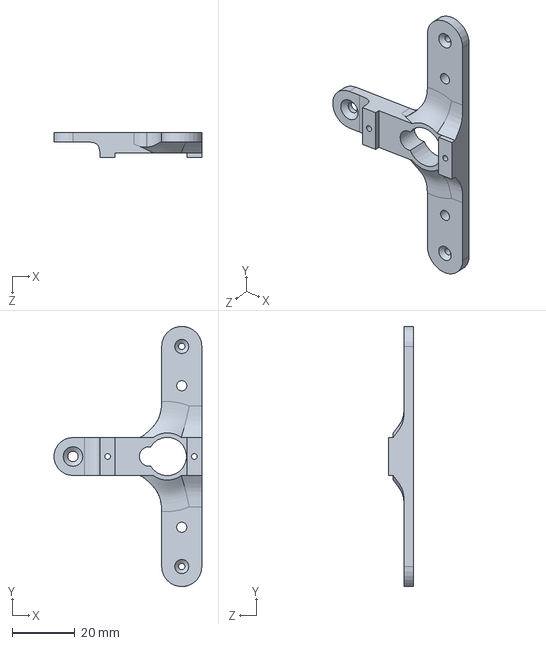
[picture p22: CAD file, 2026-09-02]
CAD/Steering__frameTop_v2.SLDPRT
47.0 x 82.7 x 8.00 mm

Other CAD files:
CAD/ASM__DifferentialGear.SLDASM
CAD/ASM_SteeringCore.SLDASM
CAD/CarrierGear_A___0.8M_36T.SLDPRT
CAD/Steering__wheelLock.SLDPRT
CAD/Battery_LIPO_1850mAh_GAONENG.SLDPRT
CAD/Bearing_MR128ZZ.SLDPRT
CAD/Bearing_MR63ZZ.SLDPRT
CAD/GearDriver__0.8M_24T.SLDPRT
CAD/GearDriver__Spacer.SLDPRT
CAD/NutRing__3M.SLDPRT
CAD/Nut__M2_Countersunk_L10mm.SLDPRT
CAD/Nut__M3_Countersunk_L12mm.SLDPRT
CAD/Nut__M3_Countersunk_L8mm.SLDPRT
CAD/Nut__M3_Female_.SLDPRT
CAD/Nut__M3_L27.5_.SLDPRT
CAD/Nut__M3_StandOff_10mm_MaleFemale.SLDPRT
CAD/Nut__M3_StandOff_12mm.SLDPRT
CAD/Nut__M3_StandOff_30mm_MaleFemale.SLDPRT
CAD/RaspberryPi5_Case_A.SLDPRT
CAD/RaspberryPi5_Case_B.SLDPRT
CAD/Spacer_2.5mm.SLDPRT
CAD/Steering__bearing_extention.SLDPRT
CAD/Steering__frameBottom.SLDPRT
CAD/Steering__rubberWheels.SLDPRT
CAD/Steering__wheelAxle.SLDPRT
CAD/WheelLock_A.SLDPRT
CAD/WheelLock_B.SLDPRT
CAD/_____Prj_iLARP_____.3mf

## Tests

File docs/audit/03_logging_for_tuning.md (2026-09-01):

# Audit Report 3 — Logging for Tuning

Question this report answers: **after a failed run, can the team explain what
happened and re-tune from the logs alone, without re-running the robot?**
Depends on reports 01/02. Read-only audit; no source files were modified.

Ground truth for what is actually logged: `code/modules/logging/log_types.hpp`
(`TelemetryRow`, `CornerRow`, `WallRow`), `code/modules/logging/log_types.cpp`
(`telemetry_csv_header()`, `make_telemetry_row()`), and the two call sites in
`code/app/_challenge/open/main.cpp` / `code/app/_challenge/obstacle/main.cpp`.

---

## 1. D1 — Column coverage matrix

Rows = every tunable parameter in `NavigationConfig`, `StanleyConfig`,
`PIDConfig` (×3: `stanley.heading_pid`, `turn_heading_pid`, `speed_pid`), and
`ObstacleConfig`. "Observable" is applied strictly, per the plan: the log must
show the parameter's *effect*, not just a combined downstream number.

| Parameter | Effect observable in telemetry? | Column(s) | If not, what's missing |
|---|---|---|---|
| `target_outer_distance_m` | Yes | `outer_distance_m`, `distance_error_m` | — |
| `follow_corridor_center` | Yes | `corridor_center_active`, `inner_distance_m` | — |
| `search_center_kp` | Partial | `steering_rad` during `SEARCH_DIRECTION` rows | The centring *error* itself (`right_distance - left_distance` before the kp multiply) is not logged; only the final steering is, so `search_center_kp`'s effect is entangled with the clamp and cannot be isolated. |
| `search_preserve_initial_offset` | No | — | Neither the latched `search_initial_center_error_m_` nor a flag indicating the latch is active is logged anywhere; F-15's failure mode is invisible in telemetry. |
| `stanley.k` (cross-track gain) | **No** | `raw_steering_rad` (combined) | `raw_steering_rad` is `heading_term + cross_track_term` already summed inside `StanleyController::calculate`; the plan's own example (`stanley.k` needs the cross-track term seen *separately* from the heading term) is exactly this case. Neither term is logged individually. |
| `stanley.softening_speed_mps` | No | — | Same as above — folds into the un-separated cross-track term. |
| `stanley.max_steering_rad` | Partial | `steering_rad` saturating at a constant | Saturation is visible only as "steering_rad stops changing at a fixed value," which is ambiguous with `max_steering_rate_rad_s` slew-limiting or `maximum_steering_command_deg` actuator clamp reaching the same visual plateau. |
| `stanley.heading_pid.{kp,ki,kd}` | **No** | `raw_steering_rad`, `angle_error_rad` (input, not output) | The PID's own output (`heading_term`) and its integral value are not logged; only its *input* (`angle_error_rad`) and the *combined* output with the cross-track term are. Cannot separate kp/ki/kd contributions. |
| `search_front_slowdown_distance_m`, `search_front_minimum_distance_m`, `search_minimum_speed_mps` | Partial | `target_speed_mps`, `front_wall_valid` | The front-wall distance driving the slowdown is not logged during `SEARCH_DIRECTION` (only `outer_distance_m`/etc. from `NORMAL`); effect inferable only indirectly from the speed trace. |
| `approach_distance_m` | Yes | `active_approach_speed_mps`, `target_speed_mps` vs position | — |
| `turn_trigger_distance_m` | Yes | `effective_turn_trigger_m`, `front_wall_valid` | — |
| `turn_rearm_distance_m` | **No** | — | `state_.turn_armed` itself is never logged (no `TelemetryRow` field); the rearm gate's effect (F-10-adjacent "stuck disarmed" risk) is invisible. |
| `turn_preview_time_s` | Partial | `effective_turn_trigger_m` (already includes the preview term, not separable) | — |
| `turn_trigger_confirm_frames` | **No** | — | `turn_trigger_frames_` (the live counter) is not logged; only the resulting `wall_corner_trigger_active`/`front_wall_fallback_active` booleans are, once the count clears the threshold. |
| `use_wall_corner_trigger`, `front_wall_fallback_distance_m` | Yes | `wall_corner_trigger_active`, `front_wall_fallback_active` | — |
| `lidar_lateral_offset_m`, `lidar_forward_offset_m` | Partial | `wall_corner_lateral_m`/`wall_corner_forward_m` (already include the offset, not separable from the raw candidate) | — |
| `wall_corner_to_path_offset_m` | Yes | `effective_turn_trigger_m` (`calculate_geometric_turn_trigger_m` folds it in — same non-separability caveat as above) | — |
| `wall_corner_min_forward_m`, `wall_corner_max_forward_m`, `wall_corner_min_inner_length_m` | **No** | — | These are gates inside `find_inner_wall_corner_candidate`; a candidate rejected by them looks identical in the log to "no inner wall segment at all" (`wall_corner_candidate_valid=false` either way). |
| `wall_corner_stability_tolerance_m` | Partial | `wall_corner_stability_error_m` | The error is logged, but the *threshold* it is compared against is not in the row (must be cross-referenced against source/config offline). |
| `wall_corner_association_distance_m`, `wall_corner_filter_weight` | **No** | — | No column distinguishes "confirmed and freshly associated" from "confirmed and coasting on missed frames" beyond `wall_corner_confirmed`(bool). |
| `wall_corner_collinear_angle_rad`, `wall_corner_collinear_offset_m`, `wall_corner_continuation_gap_m` | **No** | — | `has_forward_wall_continuation`'s reject/accept decision is not logged at all; cannot tell offline why a candidate was rejected as "wall continues forward." |
| `wall_corner_confirm_frames` | Yes | `wall_corner_confirm_frames` | — |
| `wall_corner_max_missed_frames` | **No** | — | `wall_corner_missed_frames_` (the live counter) is not logged. |
| `wheelbase_m`, `corner_radius_m` | Partial | `turn_feedforward_rad` (combined effect) | The two constants' individual values are not logged (they are static per-run, so a config dump would suffice — see D5). |
| `turn_entry_blend_rad`, `turn_exit_blend_rad`, `exit_acceleration_blend_rad` | Partial | `turn_feedforward_rad`, `turn_progress` (post-blend combined values) | The blend *weights* themselves (`entry_weight`/`exit_weight`/`exit_acceleration_weight`) are not logged, only their end effect on the feedforward/speed — this is exactly the kind of column that would have made F-01/S1 visible from a single log (a flat `exit_acceleration_weight≈1` trace for the whole turn would have been an immediate tell). |
| `turn_heading_pid.{kp,ki,kd}` | **No** | `heading_tracking_error_rad` (input, not output), `turn_feedforward_rad` (feed-forward only, PID term not separated) | Same separability gap as `stanley.heading_pid`. |
| `heading_tolerance_rad`, `heading_confirm_frames` | Yes | `heading_error_rad`, mode transitions in `events.log` | — |
| `clockwise_turn_delta_rad`/`counter_clockwise_turn_delta_rad`, `heading_to_steering_sign` | Yes (indirectly) | Sign of `turn_feedforward_rad`/`steering_rad` vs `direction` in `events.log` | — |
| `search_speed_mps`, `normal_speed_mps`, `approach_speed_mps`, `turning_speed_mps`, `lost_wall_speed_mps` | Yes | `active_normal_speed_mps`, `active_approach_speed_mps`, `target_speed_mps`, `raw_target_speed_mps` | — |
| `enable_replay_speed_factors`, `lap2_speed_factor`, `lap3_speed_factor`, `replay_approach_factor_weight`, `maximum_replay_speed_mps` | Yes | `replay_speed_factor`, `active_normal_speed_mps`, `active_approach_speed_mps` | — |
| `replay_turn_gate_distance_m`, `replay_front_safety_override_distance_m` | **No** | — | The gate's activation (F-10) is entirely invisible: no column shows `trigger_condition` was forced `false` by the replay gate specifically (as opposed to simply not yet true). |
| `max_heading_hold_s` | Yes | `heading_hold_active`, `lost_wall_time_s` | — |
| `max_lateral_acceleration_mps2` | Yes | `corner_speed_mps` | — |
| `steering_filter_time_constant_s`, `max_steering_rate_rad_s` | Yes | `raw_steering_rad` vs `steering_rad` (before/after conditioning) | This is the one place the design explicitly succeeds at the "raw vs shaped" standard (`docs/logging/README.md` §4). |
| `max_acceleration_mps2`, `max_deceleration_mps2` | Yes | `raw_target_speed_mps` vs `target_speed_mps` | — |
| `speed_pid.{kp,ki,kd}` | **No** (and moot per F-09) | `target_acceleration_mps2` (combined, and never actuated) | Same non-separability as the other two PIDs, compounded by F-09: even a perfect log of this PID's internals would not explain robot *motion*, since the value never reaches the actuator. |
| `nominal_update_period_s`, `min_update_period_s`, `max_update_period_s` | Partial | `update_dt_s` (already clamped) | The pre-clamp raw `dt_s` is not recoverable — see D2 item 7. |
| `total_turns` | Yes (indirectly) | `lap`, `corner_index`, `FINISHED` transition in `events.log` | — |
| **`ObstacleConfig`** (all fields: `activation_distance_m`, `release_forward_m`, `pass_clearance_m`, `minimum_lookahead_m`, `avoidance_speed_mps`, `maximum_avoidance_steering_rad`, `emergency_distance_m`, `emergency_speed_mps`, `emergency_steering_rad`, `observation_merge_distance_m`, `confirmation_frames`, `maximum_confirmation_missed_frames`) | **No** | `obstacle_count` only (a raw LiDAR-obstacle count, not the fused/avoidance state) | See D2 item 1 — none of `ObstacleStatus`'s fields (`active`, `color`, `pass_side`, `forward_m`, `right_m`, `target_right_m`, `steering_rad`, `confidence`) are written to `TelemetryRow`/CSV at all; they exist only in the obstacle app's console print every 250 ms. Every `ObstacleConfig` field is therefore untunable from logs alone. |

**Summary:** distance/speed-profile parameters (turn triggers, approach/corner
speed, output-shaping rate limits) are well covered under the plan's strict
standard. All three PID controllers fail the strict standard — none logs its
proportional/integral/derivative terms separately, only combined outputs
and/or raw inputs. The entire Obstacle Challenge tunable surface
(`ObstacleConfig`) is unobservable from the CSV.

---

## 2. D2 — Blind spots

| # | Item | Status | Column(s) if present |
|---|---|---|---|
| 1 | Obstacle-avoidance state (active flag, colour, pass side, relative forward/right, target offset, avoidance steering, confidence, *why* activated/released) | **MISSING** | None. `ObstacleStatus` (`obstacle_controller.hpp:29-40`) is fully populated in memory every tick but never passed into `logging::make_telemetry_row(...)` (`obstacle/main.cpp:332-333` passes only `fused.obstacles.size()` as `obstacle_count`). `event_log->event(...)` records only the two string events "obstacle avoidance activated"/"released" (`obstacle/main.cpp:285-292`) — a timestamp and a sentence, not the state itself, and not in the per-tick CSV. Compounded by S3/F-02: during the very ticks avoidance is active, `TelemetryRow`'s *other* navigation fields are also all zero (default-constructed `NavigationDebug`), so an avoidance event is a near-total blackout in `telemetry.csv`. |
| 2 | Perception fusion diagnostics (`PerceptionDiagnostics`, printed to console every 250 ms) | **MISSING** | None. `PerceptionDiagnostics` (lidar/camera input/valid/rejected counts, matched/frame-confirmed/unmatched counts, `camera_time_synchronized`) is computed every tick in `Perception::process` and printed at `obstacle/main.cpp:342-347`, but no `TelemetryRow` field carries any of it. |
| 3 | Stanley internals (cross-track term, heading term, PID integral) | **MISSING** | `angle_error_rad`/`distance_error_m` are logged (the *inputs*), and `raw_steering_rad` is logged (the *combined output*), but the individual `cross_track_term` and `heading_term` inside `StanleyController::calculate` (`stanley_controller.cpp:13-19`), and `heading_pid_`'s integral, are not separately exposed anywhere the caller could log them — `StanleyController` has no accessor for its internal PID state. |
| 4 | Turn-heading PID internals during a corner | **MISSING** | Same gap as Stanley: `heading_tracking_error_rad` (input) and `turn_feedforward_rad` (feed-forward term only) are logged; `turn_heading_pid_`'s own output and integral are folded into `steering_rad`/`raw_steering_rad` with no separate column. |
| 5 | Speed PID internals (error, integral, output) | **PARTIAL** | `target_acceleration_mps2` is the PID's *output* and is logged — but its error/integral are not, and (per F-09) the output itself is never actuated, so even this one logged field cannot be correlated against real motor behaviour. |
| 6 | Commanded vs achieved servo pulse (is `limit_servo_pulse_step` clipping?) | **PARTIAL** | `servo_pulse_us` (the *achieved*, post-step-limit value) is logged via `OutputSnapshot`. The *commanded* (pre-step-limit) `target_servo_pulse_us` computed inside `ActuatorOutput::apply` (`open_challenge_actuator.hpp:85-88`) is a local variable never returned or logged, so clipping cannot be detected from the CSV — only inferred indirectly by comparing consecutive `servo_pulse_us` deltas against the known `maximum_servo_step_us=500` constant offline. |
| 7 | Loop timing — actual iteration period; time in LiDAR vs camera processing | **PARTIAL / MISSING** | `update_dt_s` is logged, but it is explicitly the *clamped* value (`NavigationController::calculate_dt_s`, clamped to `[min_update_period_s, max_update_period_s]`). The raw, pre-clamp `dt_s` is computed locally in the same function (`navigation_controller.cpp:1084-1101`) and discarded — **not recoverable** from the log; a stalled loop iteration is indistinguishable from a normal one once clamped at 0.12 s. Time spent in LiDAR processing vs camera processing is **MISSING** entirely — no timing instrumentation around `LidarProcessor::process`/`CameraProcessor::process` was found in scope. |
| 8 | Raw or semi-raw LiDAR scan persistence | **MISSING** | Only the three *resolved* walls are logged (`WallRow`, NORMAL-mode only — see item 9). No raw `LidarPoint` array or intermediate `CartesianPoint` list is ever written to disk; a run cannot be re-processed offline with different `LidarProcessor` thresholds. |
| 9 | All fitted line segments (not only the three resolved walls) | **PARTIAL** | `WallRow` logs `left`/`right`/`front` (the three *resolved* walls) — `ProcessedLidarData::line_segments` (every fitted/merged segment, including ones `resolve_track_walls` rejected) is never logged. Debugging a mis-classified wall (e.g. why a real wall didn't get picked as `front`) is not possible offline; it would require re-running `test_lidar` live. Also note `WallLogger::record` only fires when `mode == NavigationMode::NORMAL` (`wall_logger.cpp:16`) — no wall geometry is logged during `SEARCH_DIRECTION`, `TURNING`, or obstacle avoidance at all. |
| 10 | Camera frames (annotated JPEGs, ≤ every 500 ms, only when an object is visible) | **PARTIAL** | `obstacle/main.cpp:203-233` saves an annotated capture at most every 500 ms and only when `obstacle_candidate_visible` (a LiDAR or camera object exists). A missed detection — the camera saw nothing and LiDAR saw nothing, but a human reviewing the run knows an obstacle should have been there — produces **no image at all**, since the capture is gated on a detection already having happened. Raw (non-annotated, unconditional-cadence) frames are not persisted, so a "why didn't we see it" investigation has no visual record for the exact missed moment. |
| 11 | Battery voltage during the run | **MISSING** (start/end only) | `actuators.get_voltage()` is called once before the run loop starts and once after it ends in both `main.cpp`s (e.g. `open/main.cpp:102-111` and `:437-441`); no per-tick or even periodic voltage sample exists in `TelemetryRow` or any other stream. A mid-run voltage sag (a common cause of speed/torque loss late in a run) is invisible. |
| 12 | Which turn-trigger mechanism fired (`turn_source`) | **MISSING from CSV** | `turn_source` (`"INNER_CORNER"`/`"FRONT_FALLBACK"`/`"LEGACY_FRONT"`/`"SEARCH"`) is computed and printed to console in `open/main.cpp:227-248,382-385`, but no `TelemetryRow` field carries it — only the two booleans `wall_corner_trigger_active`/`front_wall_fallback_active` are in the CSV, from which `LEGACY_FRONT` can only be inferred as "neither boolean is true" (ambiguous with "no trigger evaluated yet" in early-lap frames). |

---

## 3. D3 — Data integrity

- **Where does `AsyncCsvWriter` drop rows, oldest or newest?**
  `push()` (`async_csv_writer.cpp:58-74`): when `queue_.size() >=
  maximum_queued_rows_` (400), it does `queue_.pop_front(); ++dropped_rows_;`
  *before* `queue_.push_back(std::move(row))` — **drop-oldest**, confirmed,
  matching `docs/logging/README.md`'s description.
- **Does the CSV show a gap marker?** No. Rows are appended to the file in
  the order they are dequeued by the writer thread
  (`writer_loop`, `async_csv_writer.cpp:98-172`); a dropped row simply never
  appears. There is no sequence number, timestamp-continuity check, or
  gap-marker row in `TelemetryRow`/`WallRow`/`CornerRow`. A dropped-rows
  event is **silently non-contiguous**: `timestamp_us` will jump by more than
  one nominal period at the drop point, but nothing distinguishes that from a
  genuinely slow loop iteration (`update_dt_s` would also be large in both
  cases) unless the reader cross-references `dropped_row_count()` (only
  available in memory/console, see next point) against the CSV by hand.
- **Are dropped-row counts reported per-writer at exit? Which are checked and
  which are not?** `open/main.cpp:427-432` checks and prints
  `telemetry_log.dropped_row_count()` and `wall_log.dropped_row_count()` to
  `stderr` if either is nonzero. **`obstacle/main.cpp` does not call
  `dropped_row_count()` on either writer at all** — the obstacle-challenge
  app has no exit-time report of dropped telemetry or wall rows, even though
  both writers exist and could drop under load (and that app additionally
  writes camera-capture JPEGs and runs OpenCV processing on the same
  process, which is more likely to create I/O/CPU pressure than the
  open-challenge app). Neither app checks `EventLogger`'s drop count anywhere
  (its queue cap is a much smaller 64 rows, `telemetry_logger.cpp:73-75`,
  making it the writer most likely to silently drop under a burst of
  mode-change events).
- **What happens to the last second of data on `SIGKILL`?** `SIGKILL` cannot
  be caught (`install_stop_signal_handlers`/`notify_stop_requested` only
  handle `SIGINT`/`SIGTERM`, `telemetry_logger.cpp:27-32`, wired via
  `std::signal(SIGINT/SIGTERM, request_stop)` in both `main.cpp`s). On
  `SIGKILL` the process terminates immediately: the writer thread's periodic
  flush (`FLUSH_INTERVAL_MS=1000`, `async_csv_writer.cpp:130-145`) means up
  to ~1 second of already-*written* (via `operator<<`) but not yet
  `flush()`-ed data can be lost to OS buffering, **plus** the entire contents
  of the in-memory `queue_` at the moment of the kill (anything pushed but
  not yet dequeued by the writer thread — bounded by up to `maximum_queued_rows`
  more rows, i.e. potentially several more seconds of telemetry at ~20 Hz)
  is lost outright, since it was never written to the `ofstream` at all. This
  matches `docs/logging/README.md`'s documented durability caveat
  ("`flush()` provides OS page-cache durability, not `fsync`-level
  guarantees") but the audit plan's specific question — the in-memory queue
  contents — is a *larger* loss window than the flush-interval caveat alone
  suggests, since it stacks the flush interval on top of however much of the
  400-row queue is unwritten at kill time.
- **Is `precision(6)` fixed enough?** `to_csv_row` sets `std::ios::fixed` and
  `precision(6)` (`log_types.cpp:55-56` etc.) for every numeric field,
  **including `timestamp_us`**, which is a `std::uint64_t` streamed through
  `operator<<` — integers are unaffected by float precision/fixed-notation
  settings in `iostream`, so `timestamp_us` is written exactly (no precision
  loss). For `float` fields: 6 decimal digits after the point is generous for
  metre-scale distances (µm resolution) and for small angles in radians
  (`heading_error_rad` at 6 decimals resolves ~0.00006°, far finer than any
  sensor's real accuracy) — **no meaningful resolution loss found** for any
  field in `TelemetryRow`/`WallRow`/`CornerRow`.
- **Can `mode` (or any field) contain a comma and break CSV parsing?**
  `row.mode` is always one of the four fixed literals returned by
  `navigation_mode_name()` (`"SEARCH_DIRECTION"`, `"NORMAL"`, `"TURNING"`,
  `"FINISHED"`) — never free text, so it cannot contain a comma. `WallRow::wall_role`
  is similarly always one of the fixed literals `"LEFT"`/`"RIGHT"`/`"FRONT"`.
  No `TelemetryRow`/`WallRow`/`CornerRow` field is ever populated from
  unescaped free-form/user text in the CSV writers in scope, so **no field was
  found that can break CSV parsing** (this part of the plan's concern is
  effectively REFUTED for the current schema — but would become a real risk
  if a future column ever logged a free-text string, e.g. an OTOS error
  message, without CSV-escaping).

---
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

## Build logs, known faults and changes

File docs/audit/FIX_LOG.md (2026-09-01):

# Fix log — drive/steering control path & tuning telemetry

Tracks execution of `docs/FIX_PLAN_DRIVE_AND_LOGGING.md`.
Baseline: commit `f2fba69`, tagged **`pre-audit-fixes`**.

**Current position: Stage 0, 1 and 2 complete. Stage 3 not started.**
Stage 3 is gated on a field test — see "Next" at the bottom.

---

## Task status

| ID | Task | Status | Commit | Verified by |
|---|---|---|---|---|
| T-00 | Baseline commit | DONE (by the team) | `f2fba69` | Obstacle app and 8 modified files are tracked |
| T-01 | Tag baseline | DONE | tag `pre-audit-fixes` | `git tag` lists it |
| T-02 | `exit_acceleration_blend_rad` unit bug (F-01) | DONE | `8525b4c` | Weight recomputed at 5 heading errors |
| T-03 | `corner_radius_m` → 0.45 (F-04) | DONE | `347d5a2` | All three consumers recomputed; min-turn-radius check |
| T-04 | `turn_heading_pid` output limits (F-16) | DONE | `c945ada` | 20° + 15° = 35° < 38° clamp |
| T-05 | `plot_run.py` column names | DONE (not in repo) | — | Ran against a 75-column synthetic log; PNG renders |
| T-06 | PID / Stanley accessors | DONE | `a172af0` | `control` builds; pure addition |
| T-07 | PID internals → CSV | DONE | `3da6f88` | Header/value pairing, 75/75 aligned |
| T-08 | Turn-trigger + timing columns | DONE | `3da6f88` | same |
| T-09 | Obstacle + fusion columns | DONE | `3da6f88` | same; `obstacle/main.cpp` syntax-clean |
| T-10 | `row_index` + drop reporting | DONE | `3da6f88` | same |
| T-11…T-14 | Obstacle architecture | **NOT STARTED** | — | Gated on the Stage 1 field test |
| T-15…T-20 | Controller lifecycle | NOT STARTED | — | — |
| T-21…T-25 | Decoupling | NOT STARTED | — | — |

---

## Tuning values that moved

| Parameter | Old | New | Why |
|---|---|---|---|
| `exit_acceleration_blend_rad` | 20.0 rad (1145.9°) | 0.3491 rad (20°) | F-01 — bare literal missing the `* PI / 180` every neighbour has |
| `corner_radius_m` | 0.12 m | 0.45 m | F-04 / D2 — 0.12 m is below the vehicle's minimum turning radius (0.210 m at the 38° clamp), so the commanded arc was undrivable |
| `turn_heading_pid.min_output` / `.max_output` | ∓0.785398 (∓45°) | ∓0.261799 (∓15°) | F-16 — the per-PID limit exceeded the 38° composite clamp, so it was never the binding constraint |

### Derived quantities, before → after

| | Before | After |
|---|---|---|
| Corner feed-forward `atan2(0.16375, R)` | 53.8° (saturated the 38° clamp) | 20.0° |
| Headroom for `turn_heading_pid` | 0° | 18° |
| Lateral-accel speed limit `sqrt(0.5·R)` | 0.245 m/s | 0.474 m/s |
| Effective corner speed | 0.245 m/s | 0.280 m/s (now bound by `turning_speed_mps`) |
| Geometric turn trigger @0.28 m/s | 0.185 m | 0.498 m |
| Exit-acceleration weight at 90° heading error | 0.982 | 0.000 |

---

## Re-tuning checklist — values now stale

Every one of these was tuned against a corner that ran at ~0.44 m/s with a
permanently saturated feed-forward and a turn trigger firing 0.185 m from the
corner. All three of those facts have changed. **Do not trust these until they
have been re-checked on the track:**

| Parameter | Current | Why it is suspect |
|---|---|---|
| `turn_entry_blend_rad` | 22.5° | Tuned to soften entry into a saturated feed-forward. With 20° of feed-forward and 18° of headroom, entry is far gentler already — this may now be too slow. |
| `turn_exit_blend_rad` | 32° | Same reasoning at corner exit. |
| `heading_tolerance_rad` | 16.5° | Loosened to let turns complete despite a saturated, poorly-tracking corner. With the PID able to act, this can likely tighten. |
| `heading_confirm_frames` | 2 | Coupled to the tolerance above. |
| `approach_distance_m` | 0.90 m | Now only 0.39 m ahead of the turn trigger (was 0.72 m). The approach ramp has far less room. **Raise this before reverting `corner_radius_m` if the robot arrives too fast.** |
| `turn_heading_pid.kp` | 0.30 | Tuned when the PID's output was being discarded by the clamp for most of every corner. It now has real authority; 0.30 is likely too low. |
| `turning_speed_mps` | 0.28 | Not stale, but see headroom below. |

### Available headroom (do not apply blind)

`max_lateral_acceleration_mps2 = 0.50` is no longer the binding constraint on
corner speed — `turning_speed_mps = 0.28` is. If grip allows, `turning_speed_mps`
can rise toward **~0.47 m/s** before the lateral limit binds again. This is a
future tuning session, not part of this plan, and it needs tyre-grip testing on
the real competition surface.

---

## Telemetry schema change

`telemetry.csv` grew from 50 to **75 columns**. New columns, by the blind spot
they close:

- **Controller internals:** `stanley_cross_track_term_rad`,
  `stanley_heading_term_rad`, `stanley_heading_integral`,
  `turn_heading_pid_output_rad`, `turn_heading_pid_integral`
- **Turn trigger:** `turn_trigger_source` (0 none / 1 inner-corner /
  2 front-fallback / 3 legacy-front), `turn_trigger_frames`, `turn_armed`,
  `replay_gate_suppressed`
- **Timing:** `raw_update_dt_s` (pre-clamp)
- **Obstacle avoidance:** `obstacle_active`, `obstacle_color`,
  `obstacle_pass_side`, `obstacle_forward_m`, `obstacle_right_m`,
  `obstacle_target_right_m`, `obstacle_steering_rad`, `obstacle_confidence`,
  `obstacle_world_x_m`, `obstacle_world_y_m`
- **Fusion:** `lidar_valid_count`, `camera_valid_count`, `matched_count`,
  `frame_confirmed_count`, `camera_time_synchronized`
- **Integrity:** `row_index`

Deliberately **not** added: `speed_pid_*`, because D5/T-16 deletes that
controller. Deliberately **deferred**: `segments.csv` and raw-scan capture —
raw scan is ~272 KB/s even in binary and needs a storage-bandwidth decision.

---

## Deviations from the plan

1. **Stage 2 was reordered.** The plan put T-05 (`plot_run.py`) first; it was
   done last instead, so the plotter could be fixed once against the final
   75-column header rather than twice.
2. **T-09 added world coordinates** (`obstacle_world_x_m/y_m`) beyond the
   audit's robot-relative proposal, so `plot_run.py`'s existing obstacle
   scatter can be driven from `telemetry.csv` directly. This removes the need
   for the `obstacles.csv` that the plotter expected and the robot never wrote.

## Known gaps

- **`plot_run.py` is not version-controlled.** It lives at
  `/home/jukkruw/iLARP/plot_run.py`, outside the repository, so the T-05 fix is
  not captured in any commit and is not reproducible for anyone else. Consider
  moving it (and `gen_sample.py`) to `tools/` inside the repo — this is also
  worth points under rubric criterion 5.
- **`gen_sample.py` was not updated.** It still generates the old
  `pos_x`/`pos_y`/`speed_mps` schema plus a fabricated `obstacles.csv`, so it no
  longer matches what `plot_run.py` reads. Either update it to emit the real
  75-column header or delete it.
- **Nothing here has run on hardware.** All verification was arithmetic,
  compilation, and a synthetic-log round-trip.

---

## Next

1. **Run one Open Challenge session** with the Stage 1 changes. The single most
   important thing to watch: **is the inner-wall corner reliably detected at
   ~0.50 m?** The turn now triggers 2.7× further out than before, and that is a
   detection question the source cannot answer. Check `turn_trigger_source` and
   `wall_corner_forward_m` in the new telemetry.
2. **Run the two checks in `HARDWARE_CHECKS.md`** (~10 minutes). Check 2 becomes
   load-bearing during Stage 3.
3. Then start Stage 3 (T-11 → T-14), the obstacle-avoidance restructure.

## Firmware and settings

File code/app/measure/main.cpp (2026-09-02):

// measure -- automated hardware-characterisation bench harness.
//
// One binary, four sub-modes, each of which commands the vehicle through a
// scripted routine and writes a CSV so the numbers that block the motion model
// (M-4 curvature_gain, M-7 speed model, M-8 coast-down, M-11 LiDAR noise) come
// from repeatable machine measurements instead of by hand.
//
//   --speed-sweep    M-7 + M-4: grid of raw wheel RPM x steering angle. Holds
//                    each cell, logs steady-state OTOS speed / yaw rate /
//                    acceleration. Straight cells give the command->speed ratio
//                    (STM32 RPM-scale error); turning cells give curvature_gain.
//   --coast-down     M-8: spin up straight, disable the motors (true free roll,
//                    NOT brake), log the deceleration to rest.
//   --lidar-noise    M-11: motors off, capture N scans, log per-scan wall
//                    distances and point-rejection tallies (sensor noise floor).
//   --lidar-capture  Motors off, hand-push the robot; dump raw scan points plus
//                    the OTOS motion per scan so analyze_measure.py can render
//                    the before/after deskew comparison.
//
// This talks to spi::SPI and otos::OTOS directly rather than through the
// open-challenge ActuatorOutput: the bench needs raw RPM commands and a real
// coast (M_DISABLE), and the challenge actuator deliberately exposes neither.
//
// Safety: SIGINT/SIGTERM brake the motors and centre the servo before exit; a
// countdown precedes every routine that moves the wheels; any SPI/OTOS failure
// mid-routine brakes and aborts. The OTOS error we measured on this unit is
// corrected at startup (--otos-scalar, default 1.0956, clamped to the device
// band) so the logged speed and distance are trustworthy ground truth.
//
// Analyse the CSVs with code/tools/analyze_measure.py.

#include <algorithm>
#include <chrono>
#include <cmath>
#include <csignal>
#include <cstdint>
#include <cstdio>
#include <cctype>
#include <cstdlib>
#include <ctime>
#include <filesystem>
#include <fstream>
#include <iostream>
#include <optional>
#include <poll.h>
#include <sstream>
#include <string>
#include <termios.h>
#include <thread>
#include <unistd.h>
#include <vector>

#include "kinematics.hpp"
#include "lidar_module.hpp"
#include "lidar_processor.hpp"
#include "otos.hpp"
#include "servo_pulse.hpp"
#include "spi_master.hpp"

namespace {

volatile std::sig_atomic_t g_running = 1;
void signal_handler(int) { g_running = 0; }

// SparkFun OTOS setLinearScalar hardware limits.
constexpr float SCALAR_MIN = 0.872f;
constexpr float SCALAR_MAX = 1.127f;

constexpr float PI = 3.14159265358979323846f;

std::uint64_t now_us() {
	return static_cast<std::uint64_t>(
		std::chrono::duration_cast<std::chrono::microseconds>(
			std::chrono::steady_clock::now().time_since_epoch())
			.count());
}

// Sleep in short slices so SIGINT is honoured promptly during long holds.
// Returns false if a stop was requested while waiting.
bool interruptible_sleep_s(float seconds) {
	const std::uint64_t deadline = now_us() +
		static_cast<std::uint64_t>(std::max(0.0f, seconds) * 1e6f);
	while (g_running && now_us() < deadline) {
		std::this_thread::sleep_for(std::chrono::milliseconds(5));
	}
	return g_running != 0;
}

// Puts the terminal in non-canonical, no-echo mode for the tool's lifetime so
// single keypresses (a/q) are read without waiting for Enter. Restores the old
// mode on destruction. A no-op if stdin is not a TTY.
class TerminalRawMode {
  public:
	TerminalRawMode() {
		if (!isatty(STDIN_FILENO) || tcgetattr(STDIN_FILENO, &old_term_) != 0) {
			return;
		}
		termios raw = old_term_;
		raw.c_lflag &= ~(ICANON | ECHO);
		raw.c_cc[VMIN] = 0;
		raw.c_cc[VTIME] = 0;
		if (tcsetattr(STDIN_FILENO, TCSANOW, &raw) == 0) {
			active_ = true;
		}
	}
	~TerminalRawMode() {
		if (active_) {
			tcsetattr(STDIN_FILENO, TCSANOW, &old_term_);
		}
	}

  private:
	termios old_term_{};
	bool active_{false};
};

bool poll_key(char &key) {
	pollfd fd{};
	fd.fd = STDIN_FILENO;
	fd.events = POLLIN;
	if (poll(&fd, 1, 0) <= 0 || !(fd.revents & POLLIN)) {
		return false;
	}
	return read(STDIN_FILENO, &key, 1) == 1;
}

// Block until one of `accept` is pressed (case-insensitive), returning the
// lowercased char. Returns 0 if interrupted (SIGINT/SIGTERM). If stdin is not a
// TTY the gate is skipped and the first accepted char is returned so the tool
// still runs non-interactively.
char wait_for_key(const std::string &accept) {
	if (!isatty(STDIN_FILENO)) {
		return accept.empty() ? 0 : accept.front();
	}
	while (g_running) {
		char key = 0;
		if (poll_key(key)) {
			const char lowered =
				static_cast<char>(std::tolower(static_cast<unsigned char>(key)));
			if (accept.find(lowered) != std::string::npos) {
				return lowered;
			}
		}
		std::this_thread::sleep_for(std::chrono::milliseconds(10));
	}
	return 0;
}

std::vector<float> parse_float_list(const std::string &text) {
	std::vector<float> values;
	std::stringstream stream(text);
	std::string token;
	while (std::getline(stream, token, ',')) {
		if (token.empty()) {
			continue;
		}
		try {
			values.push_back(std::stof(token));
		} catch (const std::exception &) {
			// Skip malformed tokens; the caller validates the resulting list.
		}
	}
	return values;
}

enum class Mode { NONE, SPEED_SWEEP, COAST_DOWN, LIDAR_NOISE, LIDAR_CAPTURE };

struct Config {
	Mode mode{Mode::NONE};

	// OTOS
	float otos_scalar{1.0956f}; // correction measured on this unit (true/report)

	// Vehicle geometry (measurements, kept in sync with kinematics.hpp).
	float wheel_diameter_m{0.0525f};
	float wheelbase_m{0.16375f};
	std::uint16_t max_wheel_rpm{1500};

	// Speed sweep grid. Within the competition operating range (<=300 RPM).
	std::vector<float> sweep_rpms{50, 75, 100, 125};
	std::vector<float> sweep_steer_deg{0};
	float dwell_s{2.5f};   // hold time per cell
	float settle_s{1.0f};  // leading slice the analyser discards (transient)
	float pause_s{2.0f};   // stopped gap between cells (decel captured too)
	float max_speed_mps{0.4f}; // hard OTOS speed limit for this 2 m test lane
	float distance_limit_m{2.0f}; // stop a cell before it can leave the test lane

	// Coast-down. At the competition speed (<=300 RPM), not beyond.
	float coast_rpm{125.0f};
	float coast_stop_speed_mps{0.03f};
	float coast_timeout_s{6.0f};

	// LiDAR.
	int scans{200};              // lidar-noise
	int capture_scans{20};       // lidar-capture
	std::string lidar_port{"/dev/ttyAMA0"};

	// Servo mapping (matches open_challenge::ActuatorConfig defaults).
	actuator::ServoPulseConfig servo{900, 1475, 2100, 500, 1.0f, 45.0f};

	std::string out_dir; // resolved run directory
};

// ---- OTOS -----------------------------------------------------------------

struct OtosSample {
	std::uint64_t t_us{0};
	float x{0}, y{0}, h{0};
	float vx{0}, vy{0}, speed{0}, yaw_rate{0};
	float ax{0}, ay{0};
};

bool read_otos(otos::OTOS &otos, OtosSample &out) {
	sfe_otos_pose2d_t pos{};
	sfe_otos_pose2d_t vel{};
	sfe_otos_pose2d_t acc{};
	if (otos.getPosVelAcc(pos, vel, acc) != ksfTkErrOk) {
		return false;
	}
	out.t_us = now_us();
	out.x = pos.x;
	out.y = pos.y;
	out.h = pos.h;
	out.vx = vel.x;
	out.vy = vel.y;
	out.speed = std::hypot(vel.x, vel.y);
	out.yaw_rate = vel.h;
	out.ax = acc.x;
	out.ay = acc.y;
	return true;
}

bool setup_otos(otos::OTOS &otos, const Config &config, float &applied_scalar) {
	std::cout << "Initializing OTOS...\n";
	if (!otos.initialize(1)) {
		std::cerr << "OTOS initialize failed\n";
		return false;
	}
	otos.setLinearUnit(kSfeOtosLinearUnitMeters);
	otos.setAngularUnit(kSfeOtosAngularUnitRadians);

	std::cout << "Keep the robot still: calibrating OTOS IMU...\n";
	if (otos.calibrateImu(255, true) != ksfTkErrOk) {
		std::cerr << "OTOS IMU calibration failed\n";
		return false;
	}

	const float requested = config.otos_scalar;
	const float clamped = std::clamp(requested, SCALAR_MIN, SCALAR_MAX);
	if (std::abs(clamped - requested) > 1e-4f) {
		std::cerr << "warning: --otos-scalar " << requested
				  << " is outside the device band [" << SCALAR_MIN << ", "
				  << SCALAR_MAX << "]; clamping to " << clamped << '\n';
	}
	applied_scalar = clamped;
	if (otos.setLinearScalar(clamped) != ksfTkErrOk) {
		std::cerr << "warning: setLinearScalar failed; logged distances will "
					 "carry the raw OTOS error\n";
		applied_scalar = 1.0f;
	} else {
		std::cout << "Applied OTOS linear scalar " << clamped
				  << " (measured correction for this unit)\n";
	}

	if (otos.resetTracking() != ksfTkErrOk) {
		std::cerr << "OTOS resetTracking failed\n";
		return false;
	}
	return true;
}

// Recalibrate the IMU and re-zero tracking on a device already brought up by
// setup_otos(). The linear scalar persists on the device, so it is not
// re-applied. Needed between cells when the field is small enough that the robot
// must be carried back to the start: recalibrate while it sits still there.
bool recalibrate_otos(otos::OTOS &otos) {
	std::cout << "Keep the robot still: recalibrating OTOS IMU...\n";
	if (otos.calibrateImu(255, true) != ksfTkErrOk) {
		std::cerr << "IMU recalibration failed\n";
		return false;
	}
	if (otos.resetTracking() != ksfTkErrOk) {
		std::cerr << "resetTracking failed\n";
		return false;
	}
	std::cout << "OTOS recalibrated and re-zeroed.\n";
	return true;
}

// ---- Motors ---------------------------------------------------------------
//
// Mirrored twin-N20 drive: both M1 and M2 take the SAME signed RPM for one
// command (the shafts are mounted to spin opposite), matching the challenge
// write_motor_rpm(). A bench command is raw: no motor_rpm_command_scale, so the
// sweep measures the true command->speed relation.
class Motors {
  public:
	explicit Motors(spi::SPI &bus) : bus_(bus) {}

	bool command_rpm(std::int16_t rpm) {
		const std::int16_t clamped = std::clamp<std::int16_t>(rpm, -1500, 1500);
		const bool m1 = bus_.set_motor_speed(spi::Motor::M1, clamped);
		const bool m2 = bus_.set_motor_speed(spi::Motor::M2, clamped);
		last_rpm_ = clamped;
		return m1 && m2;
	}

	bool brake() {
		const bool m1 = bus_.set_motor_speed(spi::Motor::M1, 0);
		const bool m2 = bus_.set_motor_speed(spi::Motor::M2, 0);
		const bool br = bus_.brake();
		last_rpm_ = 0;
		return m1 && m2 && br;
	}

	// True free roll: M_DISABLE releases the closed-loop hold so the vehicle
	// coasts instead of actively resisting motion at commanded 0 RPM.
	bool coast() {
		last_rpm_ = 0;
		return bus_.disable_motors();
	}

	std::int16_t last_rpm() const { return last_rpm_; }

  private:
	spi::SPI &bus_;
	std::int16_t last_rpm_{0};
};

bool set_steering(spi::SPI &bus, const Config &config, float steer_deg) {
	const float steer_rad = steer_deg * PI / 180.0f;
	const std::uint16_t pulse =
		actuator::to_servo_pulse_us(config.servo, steer_rad);
	return bus.set_servo_pulse_us(pulse);
}

// Gate a routine that moves the wheels. [a] run, [c] recalibrate OTOS (carry the
// robot back to the start and hold still first -- for small fields), [q] abort.
// Loops on [c]. Returns true to proceed, false on [q]/interrupt. Non-TTY runs
// proceed immediately.
bool wait_to_start(const char *what, otos::OTOS &otos) {
	while (g_running) {
		std::cout << "\n" << what
				  << "\n  [a] run   [c] recalibrate OTOS (hold still)   [q] quit "
					 ": "
				  << std::flush;
		const char key = wait_for_key("acq");
		if (key == 'c') {
			recalibrate_otos(otos);
			continue;
		}
		if (key == 'a') {
			std::cout << "GO\n";
			return true;
		}
		std::cout << "\n";
		return false; // 'q' or interrupted
	}
	return false;
}

// ---- CSV ------------------------------------------------------------------

std::string make_run_dir(const std::string &mode_name) {
	const std::uint64_t stamp =
		static_cast<std::uint64_t>(std::time(nullptr));
	const std::string dir =
		"logs/measure/" + mode_name + "_" + std::to_string(stamp);
	std::error_code ec;
	std::filesystem::create_directories(dir, ec);
	if (ec) {
		std::cerr << "warning: could not create " << dir << " (" << ec.message()
				  << "); writing to current directory\n";
		return ".";
	}
	return dir;
}

void write_meta(const Config &config, const std::string &mode_name,
	float applied_scalar) {
	const std::string path = config.out_dir + "/meta.json";
	std::ofstream meta(path);
	if (!meta) {
		std::cerr << "warning: cannot write " << path << '\n';
		return;
	}
	meta << "{\n"
		 << "  \"mode\": \"" << mode_name << "\",\n"
		 << "  \"otos_linear_scalar_applied\": " << applied_scalar << ",\n"
		 << "  \"wheel_diameter_m\": " << config.wheel_diameter_m << ",\n"
		 << "  \"wheelbase_m\": " << config.wheelbase_m << ",\n"
		 << "  \"max_wheel_rpm\": " << config.max_wheel_rpm << ",\n"
		 << "  \"dwell_s\": " << config.dwell_s << ",\n"
		 << "  \"settle_s\": " << config.settle_s << ",\n"
		 << "  \"max_speed_mps\": " << config.max_speed_mps << ",\n"
		 << "  \"distance_limit_m\": " << config.distance_limit_m << ",\n"
		 << "  \"servo_center_pulse_us\": " << config.servo.servo_center_pulse_us
		 << ",\n"
		 << "  \"maximum_steering_command_deg\": "
		 << config.servo.maximum_steering_command_deg << "\n"
		 << "}\n";
	std::cout << "Wrote " << path << '\n';
}

const char *kMotionHeader =
	"t_us,combo_index,phase,cmd_wheel_rpm,servo_pulse_us,steer_deg,"
	"x_m,y_m,h_rad,vx_mps,vy_mps,speed_mps,yaw_rate_rps,ax_mps2,ay_mps2\n";

void write_motion_row(std::ofstream &csv, const OtosSample &s, int combo,
	const char *phase, std::int16_t cmd_rpm, std::uint16_t servo_pulse_us,
	float steer_deg) {
	csv << s.t_us << ',' << combo << ',' << phase << ',' << cmd_rpm << ','
		<< servo_pulse_us << ',' << steer_deg << ',' << s.x << ',' << s.y << ','
		<< s.h << ',' << s.vx << ',' << s.vy << ',' << s.speed << ','
		<< s.yaw_rate << ',' << s.ax << ',' << s.ay << '\n';
}

// ---- Modes ----------------------------------------------------------------

int run_speed_sweep(spi::SPI &bus, otos::OTOS &otos, Config &config) {
	config.out_dir = make_run_dir("speed_sweep");
	float applied_scalar = 1.0f;
	if (!setup_otos(otos, config, applied_scalar)) {
		return 1;
	}
	write_meta(config, "speed_sweep", applied_scalar);
	std::ofstream csv(config.out_dir + "/data.csv");
	if (!csv) {
		std::cerr << "cannot open data.csv\n";
		return 1;
	}
	csv << kMotionHeader;

	Motors motors(bus);
	set_steering(bus, config, 0.0f);
	motors.brake();

	const std::size_t cells =
		config.sweep_rpms.size() * config.sweep_steer_deg.size();
	std::cout << "Speed sweep: " << config.sweep_rpms.size() << " RPM x "
			  << config.sweep_steer_deg.size() << " steering = " << cells
			  << " cells, " << config.dwell_s << " s hold each.\n"
			  << "NOTE: steer=0 cells drive STRAIGHT (need a long clear lane); "
				 "steered cells drive in a circle.\n"
			  << "One cell at a time: [a] run next, [c] recalibrate OTOS (carry "
				 "back to start, hold still), [q] stop.\n"
			  << "Pose is re-zeroed on every [a], so a small field is fine.\n";

	int combo = 0;
	const std::uint64_t sample_period_us = 20'000; // ~50 Hz
	bool aborted = false;
	for (float steer_deg : config.sweep_steer_deg) {
		if (aborted) {
			break;
		}
		for (float rpm : config.sweep_rpms) {
			if (!g_running) {
				break;
			}
			const std::int16_t cmd_rpm = static_cast<std::int16_t>(
				std::clamp(rpm, -static_cast<float>(config.max_wheel_rpm),
					static_cast<float>(config.max_wheel_rpm)));

			std::ostringstream prompt;
			prompt << "cell " << combo << "/" << (cells - 1) << ": " << cmd_rpm
				   << " RPM, " << steer_deg << " deg";
			if (!wait_to_start(prompt.str().c_str(), otos)) {
				aborted = true; // [q] or interrupted
				break;
			}
			// Re-zero pose so every cell's logged trajectory starts at the
			// origin -- cheap, and keeps the per-cell logs interpretable when
			// the robot is repositioned between cells on a small field.
			otos.resetTracking();

			set_steering(bus, config, steer_deg);
			interruptible_sleep_s(0.4f); // let the servo reach the angle
			if (!motors.command_rpm(cmd_rpm)) {
				std::cerr << "motor command failed; aborting\n";
				motors.brake();
				return 1;
			}
			const std::uint16_t pulse =
				actuator::to_servo_pulse_us(config.servo,
					steer_deg * PI / 180.0f);

			// Hold: log the whole window; the analyser drops the settle prefix.
			const std::uint64_t hold_end =
				now_us() + static_cast<std::uint64_t>(config.dwell_s * 1e6f);
			bool speed_limited = false;
			while (g_running && now_us() < hold_end) {
				OtosSample s;
				if (!read_otos(otos, s)) {
					std::cerr << "OTOS read failed; aborting\n";
					motors.brake();
					return 1;
				}
				write_motion_row(
					csv, s, combo, "hold", cmd_rpm, pulse, steer_deg);
				if (s.speed > config.max_speed_mps) {
					std::cerr << "SAFETY STOP: OTOS speed " << s.speed
						      << " m/s exceeded limit " << config.max_speed_mps
						      << " m/s\n";
					speed_limited = true;
					break;
				}
				if (std::hypot(s.x, s.y) >= config.distance_limit_m) {
					std::cout << "  distance limit reached; stopping cell\n";
					break;
				}
				std::this_thread::sleep_for(
					std::chrono::microseconds(sample_period_us));
			}

			// Stop and log the decel/settle gap so coast-in is captured too.
			motors.brake();
			const std::uint16_t center_pulse =
				actuator::to_servo_pulse_us(config.servo, 0.0f);
			set_steering(bus, config, 0.0f);
			const std::uint64_t pause_end =
				now_us() + static_cast<std::uint64_t>(config.pause_s * 1e6f);
			while (g_running && now_us() < pause_end) {
				OtosSample s;
				if (read_otos(otos, s)) {
					write_motion_row(
						csv, s, combo, "stop", 0, center_pulse, 0.0f);
				}
				std::this_thread::sleep_for(
					std::chrono::microseconds(sample_period_us));
			}
			++combo;
			if (speed_limited) {
				aborted = true;
			}
		}
	}

	motors.brake();
	set_steering(bus, config, 0.0f);
	std::cout << "Speed sweep done: " << config.out_dir << "/data.csv\n";
	return 0;
}
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
int main(int argc, char **argv) {
	Config config;

	for (int i = 1; i < argc; ++i) {
		const std::string opt(argv[i]);
		auto need_float = [&](float &dst) {
			if (auto v = next_float(i, argc, argv)) {
				dst = *v;
			} else {
				std::cerr << opt << " needs a number\n";
				std::exit(2);
			}
		};

		if (opt == "--help" || opt == "-h") {
			print_usage(argv[0]);
			return 0;
		} else if (opt == "--speed-sweep") {
			config.mode = Mode::SPEED_SWEEP;
		} else if (opt == "--coast-down") {
			config.mode = Mode::COAST_DOWN;
		} else if (opt == "--lidar-noise") {
			config.mode = Mode::LIDAR_NOISE;
		} else if (opt == "--lidar-capture") {
			config.mode = Mode::LIDAR_CAPTURE;
		} else if (opt == "--otos-scalar") {
			need_float(config.otos_scalar);
		} else if (opt == "--wheel-d") {
			need_float(config.wheel_diameter_m);
		} else if (opt == "--lidar-port") {
			if (i + 1 < argc) {
				config.lidar_port = argv[++i];
			}
		} else if (opt == "--rpms") {
			if (i + 1 < argc) {
				config.sweep_rpms = parse_float_list(argv[++i]);
			}
		} else if (opt == "--steer-deg") {
			if (i + 1 < argc) {
				config.sweep_steer_deg = parse_float_list(argv[++i]);
			}
		} else if (opt == "--dwell") {
			need_float(config.dwell_s);
		} else if (opt == "--settle") {
			need_float(config.settle_s);
		} else if (opt == "--pause") {
			need_float(config.pause_s);
		} else if (opt == "--max-speed") {
			need_float(config.max_speed_mps);
		} else if (opt == "--distance-m") {
			need_float(config.distance_limit_m);
		} else if (opt == "--coast-rpm") {
			need_float(config.coast_rpm);
		} else if (opt == "--coast-timeout") {
			need_float(config.coast_timeout_s);
		} else if (opt == "--scans") {
			float v = 0;
			need_float(v);
			config.scans = static_cast<int>(v);
		} else if (opt == "--capture-scans") {
			float v = 0;
			need_float(v);
			config.capture_scans = static_cast<int>(v);
		} else {
			std::cerr << "Unknown option: " << opt << "\n\n";
			print_usage(argv[0]);
			return 2;
		}
	}

	if (config.mode == Mode::NONE) {
		std::cerr << "Choose exactly one mode.\n\n";
		print_usage(argv[0]);
		return 2;
	}
	if (config.sweep_rpms.empty() || config.sweep_steer_deg.empty()) {
		std::cerr << "empty --rpms or --steer-deg list\n";
		return 2;
	}
	if (config.max_speed_mps <= 0.0f || config.distance_limit_m <= 0.0f) {
		std::cerr << "--max-speed and --distance-m must be positive\n";
		return 2;
	}

	std::signal(SIGINT, signal_handler);
	std::signal(SIGTERM, signal_handler);

	// Raw terminal for single-key [a]/[q] gating; restored on scope exit.
	TerminalRawMode terminal;

	// LiDAR-only modes never touch SPI/OTOS motion.
	if (config.mode == Mode::LIDAR_NOISE) {
		return run_lidar_noise(config);
	}

	otos::OTOS otos;
	if (config.mode == Mode::LIDAR_CAPTURE) {
		return run_lidar_capture(otos, config);
	}

	// Motion modes: bring up SPI, guarantee a stop on every exit path.
	spi::SPI bus;
	if (!bus.initialize()) {
		std::cerr << "SPI initialize failed\n";
		return 1;
	}
	Motors safety(bus);
	safety.brake();
	set_steering(bus, config, 0.0f);

	int rc = 1;
	if (config.mode == Mode::SPEED_SWEEP) {
		rc = run_speed_sweep(bus, otos, config);
	} else if (config.mode == Mode::COAST_DOWN) {
		rc = run_coast_down(bus, otos, config);
	}

	safety.brake();
	set_steering(bus, config, 0.0f);
	bus.close();
	if (!g_running) {
		std::cout << "\nInterrupted -- motors braked, servo centred.\n";
	}
	return rc;
}

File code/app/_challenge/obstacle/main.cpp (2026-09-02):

#include <algorithm>
#include <atomic>
#include <chrono>
#include <cmath>
#include <csignal>
#include <cstdint>
#include <iostream>
#include <optional>

#include <opencv2/imgcodecs.hpp>
#include <opencv2/imgproc.hpp>

#include "camera_module.hpp"
#include "camera_processor.hpp"
#include "obstacle_controller.hpp"
#include "obstacle_navigation_config.hpp"
#include "obstacle_metadata.hpp"
#include "open_challenge_actuator.hpp"
#include "open_challenge_common.hpp"
#include "perception.hpp"
#include "run_metadata.hpp"
#include "corner_plan_logger.hpp"
#include "segment_logger.hpp"
#include "telemetry_logger.hpp"
#include "track_map.hpp"
#include "wall_logger.hpp"

namespace {

std::atomic_bool stop_requested{false};

constexpr std::uint16_t SEARCH_LAUNCH_BOOST_RPM = 1500;
constexpr float SEARCH_LAUNCH_TIME_LIMIT_S = 0.3f;
constexpr float SEARCH_LAUNCH_RELEASE_SPEED_MPS = 0.18f;

void request_stop(int) {
	stop_requested.store(true);
	logging::notify_stop_requested();
}

} // namespace

int main(int, char **argv) {
	std::signal(SIGINT, request_stop);
	std::signal(SIGTERM, request_stop);

	navigation::NavigationConfig navigation_config =
		obstacle_challenge::make_navigation_config();
	navigation_config.enable_replay_speed_factors = false;

	perception::PerceptionConfig perception_config;

	perception_config.lidar_mount = {0.0f, 0.081875f, 0.0f};
	perception_config.camera_mount = {0.0f, 0.104f, 0.0f};
	perception_config.max_sensor_time_difference_us = 100'000;
	perception_config.max_bearing_difference_rad =
		8.0f * 3.14159265358979323846f / 180.0f;
	perception_config.minimum_confirmed_confidence = 0.55f;

	obstacle_challenge::ObstacleConfig obstacle_config;
	obstacle_config.wheelbase_m = navigation_config.wheelbase_m;
	obstacle_config.curvature_gain = navigation_config.curvature_gain;
	obstacle_config.maximum_combined_steering_rad =
		navigation_config.max_steering_rad;
	obstacle_config.activation_distance_m = 1.50f;
	obstacle_config.pass_clearance_m = 0.32f;
	obstacle_config.minimum_lookahead_m = 0.35f;
	obstacle_config.avoidance_speed_mps = 0.25f;
	obstacle_config.maximum_avoidance_steering_rad =
		32.0f * 3.14159265358979323846f / 180.0f;
	obstacle_config.confirmation_frames = 1;
	obstacle_config.emergency_distance_m = 0.35f;
	obstacle_config.emergency_speed_mps = 0.16f;
	obstacle_config.emergency_steering_rad =
		32.0f * 3.14159265358979323846f / 180.0f;
	camera::CameraModule camera(640, 640, 90.0f, 1.8f, 2.8f);
	camera::CameraProcessor camera_processor;
	lidar::LidarModule lidar("/dev/ttyAMA0", 1'000'000);
	lidar::LidarProcessor lidar_processor;
	perception::Perception perception(perception_config);
	otos::OTOS otos;
	navigation::NavigationController navigation(navigation_config);
	navigation::TrackMap track_map;
	obstacle_challenge::ObstacleController obstacle_controller(obstacle_config);
	open_challenge::ActuatorConfig actuator_config;
	// See open/main.cpp: the 0.571 pre-scale is disproven by LOG_5_NOOB (it
	// starved the ~0.28 m/s turning target to ~58 RPM, below the stall floor, so
	// turns froze mid-corner). No pre-scaling until measure --speed-sweep gives a
	// real command->speed map.
	actuator_config.motor_rpm_command_scale = 1.0f;
	// Stall floor: see open/main.cpp. 110 RPM (~0.30 m/s) keeps low-speed
	// commands out of the dead zone that froze the turns in LOG_5_NOOB.
	actuator_config.minimum_moving_wheel_rpm = 110;
	open_challenge::ActuatorOutput actuators(actuator_config);
	const std::uint64_t search_launch_time_limit_us =
		static_cast<std::uint64_t>(
			std::max(0.0f, SEARCH_LAUNCH_TIME_LIMIT_S) * 1'000'000.0f);

	std::cout << "Obstacle Challenge: camera + LiDAR fusion, OTOS map, SPI "
				 "active\n"
			  << "RED pass RIGHT, GREEN pass LEFT, confirmation="
			  << obstacle_config.confirmation_frames
			  << " frames, clearance=" << obstacle_config.pass_clearance_m
			  << "m\n";

	if (!camera.start()) {
		std::cerr << "Camera initialization failed\n";
		return 1;
	}
	if (!lidar.initialize() || !lidar.start()) {
		std::cerr << "LiDAR initialization failed\n";
		camera.stop();
		return 1;
	}
	if (!otos.initialize(1)) {
		std::cerr << "OTOS initialization failed\n";
		lidar.stop();
		camera.stop();
		return 1;
	}
	otos.setLinearUnit(kSfeOtosLinearUnitMeters);
	otos.setAngularUnit(kSfeOtosAngularUnitRadians);
	if (!open_challenge::calibrate_otos(otos)) {
		lidar.stop();
		camera.stop();
		return 1;
	}
	if (!actuators.initialize()) {
		std::cerr << "SPI actuator initialization failed\n";
		lidar.stop();
		camera.stop();
		return 1;
	}
	if (const auto voltage = actuators.get_voltage(); voltage.has_value()) {
		std::cout << "Battery voltage: " << *voltage << " V\n";
		if (*voltage <= 11.67f) {
			std::cerr << "Battery voltage is below 11.67 V\n";
			actuators.close();
			lidar.stop();
			camera.stop();
			return 1;
		}
	} else {
		std::cerr << "Battery voltage read failed\n";
	}

	const open_challenge::OtosScalars otos_scalars =
		open_challenge::read_otos_scalars(otos);
	const std::string run_directory = logging::make_run_directory();
	logging::JsonObject run_metadata = logging::make_run_metadata(argv[0],
		navigation_config, otos_scalars.linear, otos_scalars.angular);
	run_metadata
		.add_object("actuator_config",
			open_challenge::actuator_config_json(actuator_config))
		.add_object(
			"perception_config",
			obstacle_challenge::perception_config_json(perception_config))
		.add_object("obstacle_config",
			obstacle_challenge::obstacle_config_json(obstacle_config))
		.add_object("lidar_process_params",
			open_challenge::lidar_process_params_json(
				open_challenge::lidar_process_params()));
	if (!logging::write_run_metadata(run_directory, run_metadata)) {
		std::cerr << "Cannot write run_meta.json; refusing unattributed run\n";
		actuators.close();
		lidar.stop();
		camera.stop();
		return 1;
	}
	logging::TelemetryLogger telemetry_log(run_directory);
	logging::WallLogger wall_log(run_directory);
	logging::SegmentLogger segment_log(run_directory);
	logging::CornerPlanLogger corner_plan_log(run_directory);
	std::optional<logging::EventLogger> event_log;
	std::cout << "Logging to " << run_directory << '\n';

	bool initialized = false;
	// Battery held from a ~1 Hz sample; get_voltage() is a blocking SPI call.
	constexpr std::uint64_t BATTERY_SAMPLE_INTERVAL_US = 1'000'000;
	std::optional<float> last_battery_voltage_v;
	std::uint64_t last_battery_sample_us = 0;
	std::uint64_t launch_start_us = 0;
	bool launch_complete = false;
	std::uint64_t last_console_us = 0;
	std::uint64_t last_obstacle_capture_us = 0;
	navigation::NavigationMode previous_mode =
		navigation::NavigationMode::SEARCH_DIRECTION;

	while (!stop_requested.load()) {
		TimedLidarData scan;
		if (!lidar.wait_for_data(scan) || scan.points.empty()) {
			std::cerr << "LiDAR stream failed; emergency stop\n";
			actuators.emergency_stop();
			break;
		}
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

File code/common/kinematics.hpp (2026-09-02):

#pragma once

#include <algorithm>
#include <cmath>
#include <cstdint>

namespace kinematics {

struct ClothoidReference {
	float total_angle_rad{0.0f};
	float radius_m{0.4f};
	float ramp_length_m{0.10f};

	float total_length_m() const {
		return std::max(0.0f, radius_m) * std::abs(total_angle_rad);
	}
	float effective_ramp_m() const {
		return std::min(total_length_m() * 0.5f,
			std::max(1e-4f, ramp_length_m));
	}
	float peak_curvature_1pm() const {
		const float length = total_length_m();
		const float ramp = effective_ramp_m();
		return length > 1e-6f ? std::abs(total_angle_rad) /
			(std::max(0.0f, length - 2.0f * ramp) + ramp) : 0.0f;
	}
	float curvature_at_distance(float distance_m) const {
		const float s = std::clamp(distance_m, 0.0f, total_length_m());
		const float ramp = effective_ramp_m();
		const float plateau_end = total_length_m() - ramp;
		const float peak = peak_curvature_1pm();
		if (s < ramp) return peak * s / ramp;
		if (s <= plateau_end) return peak;
		return peak * (total_length_m() - s) / ramp;
	}
	float heading_progress_at_distance(float distance_m) const {
		const float s = std::clamp(distance_m, 0.0f, total_length_m());
		const float ramp = effective_ramp_m();
		const float plateau_end = total_length_m() - ramp;
		const float peak = peak_curvature_1pm();
		float integral = 0.0f;
		if (s <= ramp) integral = peak * s * s / (2.0f * ramp);
		else if (s <= plateau_end) integral = peak * (s - ramp * 0.5f);
		else integral = peak * (plateau_end - ramp * 0.5f) +
			peak * (s - plateau_end) *
			(1.0f - (s - plateau_end) / (2.0f * ramp));
		return integral;
	}
};

// The bicycle model, in one place.
//
// Curvature is the control stack's currency because it superposes linearly:
// a wall-following curvature and an obstacle-avoidance curvature may be added,
// whereas two steering angles may not. delta = atan(L * kappa) is nonlinear --
// the error from adding angles instead of curvatures is 4.3% at 20 deg and
// grows from there.
//
// Sign convention matches the steering convention throughout the codebase:
//   kappa < 0  curves LEFT
//   kappa > 0  curves RIGHT
//
// Nothing consumes this yet: it is introduced ahead of the migration that
// moves the controllers onto curvature, so it can be reviewed and unit-tested
// in isolation first.
struct BicycleModel {
	// Rear-axle centre to front-axle centre. A measurement, never a gain.
	float wheelbase_m{0.16375f};

	// Ratio of the curvature the vehicle actually achieves to the curvature the
	// ideal Ackermann model predicts for the same steering angle.
	//
	// 1.0 is the textbook model. This chassis measured a minimum radius of
	// 0.155 m where the geometry allows only 0.210 m at the 38 deg clamp, which
	// implies a gain near 1.35 if the clamp was active at that moment (see
	// VEHICLE_MECHANICS_REVIEW.md section 6). The leading explanation is that
	// write_motor_rpm() drives both rear motors at the same RPM, so the axle
	// cannot roll freely through a turn and scrubs, adding yaw beyond Ackermann.
	//
	// MUST stay at 1.0 until measured by the M-4 procedure. Setting it from the
	// log instead of from a floor measurement would fold OTOS angular-scale
	// error into the vehicle model.
	float curvature_gain{1.0f};

	float curvature_for_steering(float steering_rad) const {
		const float wheelbase = std::max(1e-4f, wheelbase_m);
		return curvature_gain * std::tan(steering_rad) / wheelbase;
	}

	float steering_for_curvature(float curvature_1pm) const {
		const float wheelbase = std::max(1e-4f, wheelbase_m);
		const float gain = std::max(1e-3f, curvature_gain);
		return std::atan(wheelbase * curvature_1pm / gain);
	}

	float max_curvature(float max_steering_rad) const {
		return curvature_for_steering(std::abs(max_steering_rad));
	}
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

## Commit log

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2026-08-10 Enhance LidarModule functionality and improve data handling
    - Refactor main lidar scanning logic to process and display data points.
    - Add TimedLidarData structure for better data management.
    - Update CMakeLists to include necessary directories.
    - Introduce processScan method for handling scan data.
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2026-08-17 Fix a little to camera_processor, implement cam process method
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2026-08-18 Refactor CMakeLists.txt files to remove unnecessary comments and add OpenCV include directories for lidar modules
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2026-08-20 Implement resolved track wall
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2026-08-21 Add OTOS class for I2C bus communication with initialization and delay methods
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2026-08-22 fix lidar after rotate 180
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2026-08-26 Remove test_navi application and related files; adjust LidarModule target RPM; enhance LidarProcessor to include heading error in processing; update navigation CMakeLists to include header file.
    [main.cpp]
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2026-08-28 FIX , MERGEIDAR WITH ODOMENTRY
    [main.cpp, main2.cpp]
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2026-08-31 Refactor actuator control and telemetry system
    - Updated actuator configuration to use wheel RPM instead of power percent.
    - Introduced methods for writing motor RPM and limiting servo pulse changes.
    - Enhanced telemetry structure to track wheel RPM.
    - Modified actuator output methods to handle RPM commands and telemetry updates.
    - Adjusted navigation configuration parameters for improved performance.
    - Added calibration function for OTOS IMU.
    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
2026-09-01 add CAD
    [_____Prj_iLARP_____.3mf]
2026-09-01 docs: add drive/logging audit reports and fix plan
    Adds the read-only audit of the drive/steering control path and the
    tuning-telemetry schema (docs/audit/01-03), the audit work order that
    produced them, and the remediation plan those reports feed into.
2026-09-01 fix(nav): T-03 corner_radius_m demanded an arc the vehicle cannot drive (F-04)
    Finding: F-04 -- atan2(wheelbase_m, corner_radius_m) produced a 53.8 deg
    feed-forward against a 38 deg clamp, so the feed-forward term alone
    saturated clamp_steering() and turn_heading_pid had no authority
    left mid-corner. Root cause was not a tight clamp: 0.12 m is below
    the vehicle's minimum turning radius at ANY steering angle.
    Change: open_challenge_common.hpp -- corner_radius_m 0.12f -> 0.45f (D2)
    Values: corner_radius_m 0.12 m -> 0.45 m
    Verify: with wheelbase_m = 0.16375, max_lateral_acceleration_mps2 = 0.50:
    minimum turning radius @38 deg steer = 0.210 m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
2026-09-01 fix(nav): T-04 turn_heading_pid output limit exceeded the steering clamp (F-16)
    Finding: F-16 -- turn_heading_pid's own min_output/max_output were +/-45 deg,
    wider than the 38 deg clamp applied to the summed turning-mode
    output. Reading the PID config in isolation implied 45 deg of
    authority the controller could never actually use.
    Change: navigation_controller.hpp -- turn_heading_pid min/max output
    -0.785398f/0.785398f -> -0.261799f/0.261799f
    Values: turn_heading_pid output limit +/-45 deg -> +/-15 deg
    Verify: 20.0 deg (feed-forward, post T-03) + 15 deg (PID) = 35 deg
    < 38 deg (clamp)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
2026-09-01 feat(control): T-06 expose PID and Stanley internals for telemetry (D2 #3, #4)
    Finding: audit 03 D2 #3/#4 -- neither controller exposes its own output or
    integral, so telemetry can only log the summed command. Tuning
    kp/ki/kd or Stanley's k from a combined number is guesswork.
    Change: PID gains integral() and last_output(); last_output_ is recorded at
    all three return paths in calculate() and cleared in reset().
    StanleyController gains last_cross_track_term_rad(),
    last_heading_term_rad(), and heading_integral(); the two terms are
    recorded where they are already computed and cleared in reset().
    Verify: Pure additions. No existing express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
2026-09-01 feat(logging): T-07/T-08/T-09/T-10 make the control path observable from a log
    Finding: audit 03 D1/D2 -- none of the three PID controllers logged its own
    terms, the entire ObstacleConfig surface was untunable from CSV,
    a stalled loop iteration was indistinguishable from a healthy one,
    and a dropped row left no trace in the file.
    T-07 Stanley and turn-heading PID internals reach telemetry:
    stanley_cross_track_term_rad, stanley_heading_term_rad,
    stanley_heading_integral, turn_heading_pid_output_rad,
    turn_heading_pid_integral
    Deliberately NOT adding speed_pid_* columns: D5 deletes that
    controller in T-16, so they would be added a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
    [log_types.cpp, main.cpp]
2026-09-01 docs: record decisions D1-D6, hardware checks, and the Stage 0-2 fix log
    - FIX_PLAN: all six decisions answered; maximum_steering_command_deg = 45
    confirmed real, so the steering-angle measurement is no longer outstanding.
    - HARDWARE_CHECKS: step-by-step procedures for the two frame conventions the
    source cannot settle (F-07 LiDAR angle zero, F-08 OTOS world axis), with
    blanks to fill in. Both are forbidden to act on until these come back.
    - FIX_LOG: task status through Stage 2, every tuning value that moved with
    its before/after derived quantities, the re-tuning checklist of values now
    stale because the behaviour they were tuned against has changed, the new
    75-column telemetry s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
2026-09-01 docs: fix a dangling cross-reference in the fix plan
    Ground rule 6 pointed at a "Still open" note that was removed when D1 was
    answered. It now points at HARDWARE_CHECKS.md, and the Thai preamble reports
    status instead of asking for decisions that are already made.
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2026-09-01 feat(logging): O-06 write segments.csv every tick
    Finishes the half-applied O-06 from the observability work order. The
    SegmentLogger library, SegmentRow schema, and CMake entry were already on
    disk (uncommitted); the call-site wiring in both apps had been declined by
    auto-review and never applied, so segments.csv was never produced.
    Change: Instantiate SegmentLogger in open/ and obstacle/ main, record one
    row per fitted LineSegment per tick in every mode, and report its
    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
2026-09-01 feat(logging): O-07 sample battery voltage during the run
    Finding: D2 #11 -- voltage was read only once before the loop and once after,
    so a mid-run sag (a common cause of a drifting speed profile) was
    invisible.
    Change: Add battery_voltage_v, battery_sample_age_us and battery_valid to
    TelemetryRow via an optional BatterySample. Both apps sample
    get_voltage() at ~1 Hz (it is a blocking SPI round-trip and must not
    run at loop rate), hold the last good reading between samples, and
    log its age so a stale hold is visible. A failed read never advances
    the sample time and leaves battery_valid false, so 0 V is never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
    [log_types.cpp, main.cpp]
2026-09-01 feat(logging): O-08 record per-stage processing time
    Finding: D2 #7 -- update_dt_s is the clamped loop period and raw_update_dt_s
    the pre-clamp period, but neither shows where the time went. A slow
    tick could not be attributed to LiDAR vs camera processing.
    Change: Add lidar_process_us, camera_process_us and camera_process_valid to
    TelemetryRow via an optional StageTiming. Both apps wrap
    process_scan() on the steady_clock; the obstacle app also wraps
    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
2026-09-01 feat(logging): O-09 log commanded servo pulse before the step limit
    Finding: D2 #6 -- only the post-clip servo_pulse_us was logged, so whether
    maximum_servo_step_us was clipping the steering command could only be
    inferred by differencing consecutive rows against a known constant.
    Change: ActuatorTelemetry keeps commanded_servo_pulse_us (the value from
    to_servo_pulse_us before limit_servo_pulse_step), set consistently in
    apply/initialize/emergency_stop. It flows through OutputSnapshot into
    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
2026-09-01 feat(logging): O-16 count LiDAR point rejections per scan
    Finding: is_valid_point() drops points below quality 10 and outside
    [0.015, 3.0] m at the sensor boundary, irreversibly. These are
    tuning decisions no log could second-guess.
    Change: Introduce classify_point() as the single source of truth for the
    validity gate; is_valid_point() now delegates to it so the decision
    and the rejection reason cannot diverge. process() tallies total /
    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
2026-09-01 feat(logging): O-17 log wall-heading correction and mark the frame
    Finding: process_scan() de-rotates wall resolution by heading-target before
    classification, so the logged wall_angle_rad and walls.csv angles are
    corrected geometry, not measured geometry -- correct for control,
    misleading as evidence, and the correction itself was not recorded.
    Change: Add a wall_correction_rad column set from the value both apps already
    compute, so raw geometry can be recovered offline by subtracting it.
    Note the corrected frame in docs/lidar/README.md 3.0.
    Verify: Field counts 93->94, header==row. open compiles; obstacle mirror
    block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
    [log_types.cpp, main.cpp]
2026-09-02 feat(kinematics): P-01 add BicycleModel curvature primitives
    First step of the motion-model plan. Introduces code/common/kinematics.hpp: a
    header-only BicycleModel providing curvature<->steering conversion, a
    curvature-domain rate limit that grows with |kappa| as the geometry demands, a
    lateral-acceleration speed cap, and a curvature_gain placeholder (kept at the
    textbook 1.0 until the M-4 floor measurement).
    Curvature is introduced as the control stack's future currency because it
    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
2026-09-02 feat(tools): O-12 add measure_otos_scale bench tool (test A)
    Interactive tool for the OTOS linear-scale check. Motors stay off; the operator
    zeroes tracking, pushes the robot a tape-measured distance, and marks: it prints
    OTOS reported vs true distance and the linear scalar that would correct it,
    optionally applying it with a keypress.
    Context: the wheel measured 53.5 mm (~ the configured 53), so the ~1.6x
    measured/target speed gap is not the wheel. setLinearScalar is limited to
    [0.872, 1.127], so it cannot be OTOS either -- this tool proves that directly:
    an in-band correction confirms OTOS is trustworthy ground truth, which pins the
    1.6x on the STM32 RPM scale (test C / firmware). An out-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
    [main.cpp]
2026-09-02 fix(actuator): compensate STM32 RPM scale from the Pi (no reflash)
    The STM32 turns a commanded RPM into ~1.75x the intended ground speed. Measured
    attribution: wheel is 53.5 mm (not the wheel); OTOS under-reports only 8.7% and
    is scalar-correctable (not the sensor) -- so the gap is the firmware RPM scale.
    Reflashing the STM32 is impractical, so compensate on the Pi.
    Change: Add ActuatorConfig::motor_rpm_command_scale (default 1.0, no change),
    applied in to_wheel_rpm() on the speed->RPM path only. Both apps set
    it to 0.571 (= 1/1.75). wheel_rpm_override (search-launch boost) is
    deliberately NOT scaled: it is an empirical max kick, not a speed
    ta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
    [main.cpp]
2026-09-02 docs: update logging and lidar READMEs to the current code
    docs/logging/README.md was describing a much smaller 'Logger V1': 4 streams,
    NORMAL-only walls, no run_meta.json/segments.csv, a 50-ish-column row, and 'no
    analysis scripts'. Rewrite to the shipped state -- the missing-value convention,
    run_meta.json provenance, the 94-column TelemetryRow groups (raw OTOS channels,
    battery, per-stage timing, servo pre-clip, LiDAR reject counts, wall_correction),
    all-mode walls/segments, and the plot_run.py/check_run.py tools.
    docs/lidar/README.md stated is_valid_point() drops quality < 50 or
    distance < 0.01 m; the code uses quality < 10, distance in [0.015, 3.0] m via
    classify_point(). Correct it an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
2026-09-02 docs: motion model study, unified plan, and patch recipes
    Adds the motion-model working set:
    - VEHICLE_MECHANICS_STUDY_TH.txt the theory (curvature as the common
    language, deskew, robust line fitting), labelled a study
    - MOTION_MODEL_UNIFIED_PLAN.md the analysis: identifiability rank
    argument, the withdrawn H-1 hypothesis and its methodological lesson,
    the open curvature violation, corrections to the study's numbers
    - MOTION_CORE_AND_PATCH_PLAN.md the hands-on manual: the six-layer
    equation chain, per-task patch recipes, the measurement programme,
    and a cold-start checklist
    - TUNING_WORKBENCH_BRIEF.md the off-robot analysis/tuning concept
    Supersedes the earlier MOT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
2026-09-02 docs(mechanical): P-50 correct the motor count -- two, not one
    The mechanical README described "a single DC gear-motor". The chassis has
    two N20 motors mounted mirror-imaged onto a common input, added to supply
    torque the single-motor layout could not. They join at the differential's
    input, so left/right differential action is preserved -- they are not
    one-motor-per-wheel. Clarified so the drivetrain topology reads correctly.
2026-09-02 docs: P-51/P-52 clarify drive banner and RPM-scale provenance
    P-51: the launch banner said "M1 +RPM, M2 -RPM" (shaft rotation) while
    write_motor_rpm() sends one command value to both. Neither was wrong, but
    the wording invited reading a contradiction. Reworded to state that the
    twin mirrored motors share one command and their shafts turn opposite ways.
    P-52: relabel motor_rpm_command_scale = 0.571 as a provisional single-point
    correction, not an identified gain -- the NORMAL/TURNING spread shows the
    relation is not a scalar. Points at M-3c/M-7 for the real model.
    No behavioural change: the banner is a print, the comment is a comment.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
    [main.cpp]
2026-09-02 test: P-00 make the sim tests emit a servo-pulse fingerprint
    The pulse-identical verification bar that the motion plan and the earlier
    hand-off both specify could not actually be run: navigation_corner_sim_test
    never touched the actuator pulse math, so there was no pulse sequence to
    compare across a refactor.
    - Extract the exact steering-rad -> pulse arithmetic out of ActuatorOutput
    into common/servo_pulse.hpp as free functions. ActuatorOutput now delegates
    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
2026-09-02 feat(nav): P-02 carry curvature through the command, convert at the boundary
    First step of the delta->kappa migration, and behaviour-neutral by design.
    - NavigationCommand gains curvature_1pm (appended, so existing braced inits
    are unaffected).
    - NavigationController holds one kinematics::BicycleModel, wheelbase mirrored
    from the config, curvature_gain fixed at 1.0 until M-4.
    - update() sets curvature_1pm = model.curvature_for_steering(steering_rad) at
    the point the mode handlers finish -- the boundary of the migration.
    - condition_command() reconstructs the steering angle from curvature_1pm via
    model.steering_for_curvature() and feeds the existing, unchanged shaping.
    The mode hand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
2026-09-02 feat(nav): P-03 delete the dead speed_pid / acceleration path (F-09)
    speed_pid's output flowed into NavigationCommand::target_acceleration_mps2,
    which reached no actuator -- ActuatorOutput::apply() converts target_speed_mps
    straight to an RPM command and the STM32 closes its own speed loop. The gain
    was therefore inert, and tuning it (as the control doc instructed) changed
    nothing on the robot. Removed end to end:
    - speed_pid (NavigationConfig), speed_pid_ member, its ctor init and reset()
    - target_acceleration_mps2 from NavigationCommand and NavigationDebug
    - target_acceleration_mps2 from TelemetryRow: struct field, CSV header, row
    writer, and make_telemetry_row()
    - speed_pid serialisati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
    [log_types.cpp, main.cpp, run_metadata.cpp]
2026-09-02 feat(nav): P-21b give the steering clamp its own config field (F-11)
    clamp_steering() read config.stanley.max_steering_rad, but it is the clamp
    for SEARCH, TURNING, and the final command conditioning -- none of which use
    the Stanley controller. Tuning Stanley's aggressiveness therefore silently
    re-limited every mode's steering (audit F-11).
    - Add NavigationConfig::max_steering_rad (default 38 deg, equal to the value
    the Stanley limit carried, so behaviour is unchanged).
    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
2026-09-02 docs: full tuning-variable inventory and what run_metadata captures
    Lists every tuning variable by subsystem (NavigationConfig, Stanley,
    turn_heading_pid, LidarProcessor::process args, ActuatorConfig, ObstacleConfig,
    PerceptionConfig) and marks which run_metadata.cpp already records and which it
    does not, so a log can be traced back to the values it ran with.
    Key gaps surfaced: ActuatorConfig is entirely unlogged (including
    motor_rpm_command_scale = 0.571 and the servo/steering pulse map), the six
    LidarProcessor::process magic-number args are unlogged, ObstacleConfig and the
    obstacle-app config overrides are unlogged, and ~13 NavigationConfig fields are
    missing -- notably exit_acceleration_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
2026-09-02 docs: correct the tuning-variable inventory -- everything is logged
    The first draft marked many fields "not logged"; that was wrong -- a text
    search had missed run_metadata keys wrapped onto a second line. Verified
    against every serialiser (navigation_config_json, actuator_config_json,
    obstacle_config_json, perception_config_json, otos): every config group is
    recorded in run_meta.json, and the one real gap (the LiDAR process thresholds)
    was closed in f11b581.
    Rewritten as a per-run reference: what each run_meta.json object contains, the
    current values, and the note that the obstacle app's navigation_config
    reflects its overrides. Ends with the per-run (run_meta.json) vs per-tick
    (telemetry.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
2026-09-02 feat(lidar): P-21 add motion deskew transform, disabled by default
    Implements the per-point SE(2) motion-distortion correction:
    - ScanMotion{forward_speed_mps, yaw_rate_rps, scan_period_s, valid} carries the
    body twist across a scan window, passed into process() by value so the
    processor stays pure.
    - LidarProcessor::deskew() expresses a sample taken at fraction scan_phase of
    the revolution in the scan-end frame: dt = (1-phase)*period, translate by the
    exact SE(2) displacement for the constant twist, rotate by R(-w*dt). Uses the
    straight-line limit below |w| < 1e-3 to avoid the 1/w singularity.
    - process() applies it per point only when motion.valid; the new trailing param
    defau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
